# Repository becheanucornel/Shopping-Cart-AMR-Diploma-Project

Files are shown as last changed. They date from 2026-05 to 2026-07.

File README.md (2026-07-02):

# Shopping Cart AMR — Diploma Project







Robots have undeniably made our lives better. As years pass, new types of robots appear that assist humans even more. This project's objective is to develop a mobile robot capable of helping people inside supermarkets. The robot's purpose in this scenario is to replace the conventional shopping cart — eliminating the need to push or pull it around, and enabling wheelchair users to move more freely.

The robot is capable of autonomous navigation on a pre-built map, human/object detection and following using a YOLOv8 TensorRT model running at 207 FPS on the Jetson's GPU, and full remote control via a purpose-built web interface accessible from any device on the local network.

## System Architecture

### Hardware

| Component | Details |
|---|---|
| Compute | NVIDIA Jetson Orin Nano Super (8GB unified memory) |
| Motors | 2× 12V DC motors with quadrature encoders |
| Motor Drivers | 2× H-bridge motor driver modules |
| LiDARs | 4× SLAMTEC RPLIDAR C1 (one per corner, merged into a single scan) |
| Camera | Raspberry Pi Camera Module (CSI, 640×480 @ 30fps via GStreamer/Argus) |
| Chassis | Custom-designed in SolidWorks, 360×360mm differential drive base |

### Software Stack

| Layer | Technology |
|---|---|
| Robot OS | ROS2 Humble |
| Navigation | Nav2 (AMCL + NavFn planner + Regulated Pure Pursuit controller) |
| Localization | AMCL with pre-built map + EKF sensor fusion (wheel odometry + laser odometry) |
| Laser odometry | rf2o (scan-to-scan ICP, wheel-independent) |
| Object detection | YOLOv8n → TensorRT FP16 engine (207 FPS, 4.75ms GPU latency) |
| SLAM | slam_toolbox (used during mapping mode) |
| Web interface | Custom C++ Boost.Beast HTTP/WebSocket server + rosbridge |
| Build system | colcon / CMake |

## Packages

### Community packages
- **Nav2** — autonomous navigation stack (planner, controller, costmaps, behavior trees)
- **slam_toolbox** — online async SLAM for map creation
- **sllidar_ros2** — SLAMTEC LiDAR driver
- **rf2o_laser_odometry** — laser-based odometry, used alongside wheel encoders in the EKF
- **robot_localization** — EKF node fusing `/custom_odom_topic` (encoders) and `/odom_rf2o` (laser)

### Custom packages

#### `camera_module` (C++)
Publishes the Raspberry Pi camera stream to `/camera` using GStreamer/Argus at 30fps. Uses `SensorDataQoS` (Best Effort) to match downstream subscribers.

#### `human_detection_module` (C++)
YOLOv8n inference node running on TensorRT 10.3 FP16. On first launch it builds a serialized engine from `yolov8n.onnx` (takes ~10 minutes on first run, then cached permanently at `~/.ros/human_detection/yolov8n.engine`). Subsequent launches load the cached engine in under one second.

- Subscribes to `/camera` with `SensorDataQoS`
- Publishes `/yolo/debug_image` — live camera feed with bounding boxes drawn in real time
- Publishes `/yolo/target_pose` — 3D position of the tracked object in `camera_link` frame, estimated using the focal length and bounding box height
- Exposes `/detector/set_class` service (`std_srvs/SetBool`) — `false` = track person (class 0), `true` = track sports ball (class 32), for testing without a person present
- Parameters: `confidence_threshold` (0.50), `nms_threshold` (0.45), `focal_length_px` (500)

#### `mode_manager_module` (C++)
Central state machine managing the robot's five operating modes. Receives mode commands from the web UI on `/ui/mode/absolute` and routes velocity commands from the appropriate source to `/cmd_vel`.

| Mode | Velocity source | Behaviour |
|---|---|---|
| `IDLE` | — | Motors stopped |
| `MANUAL` | `/cmd_vel_teleop` | Joystick/D-pad from web UI |
| `MAPPING` | `/cmd_vel_teleop` | Manual drive while slam_toolbox builds a map |
| `NAVIGATION` | `/cmd_vel_nav2` | Autonomous point-to-point navigation via Nav2 |
| `FOLLOWING` | `/cmd_vel_nav2` | Follows the detected target using Nav2 as the path executor |

Switching out of `MAPPING` automatically saves the map, stops slam_toolbox, and reactivates AMCL. Switching out of `NAVIGATION` or `FOLLOWING` cancels any active Nav2 goal.

#### `scan_merger_module` (C++)
Merges the four LiDAR scans (front-left, front-right, back-left, back-right) into a single `/scan` topic in the `custom_base_link` frame. Uses cached TF transforms for zero-overhead merging at runtime.

#### `web_server` (C++)
Custom HTTP server built with Boost.Beast that hosts the robot control interface. No external web server or framework needed — the binary serves static files and handles all API calls and MJPEG streams directly.

Endpoints:
- `GET /` — main control page
- `GET /stream/camera` — MJPEG stream of the raw `/camera` topic (~20 FPS cap)
- `GET /stream/debug` — MJPEG stream of `/yolo/debug_image` with bounding box overlay
- `GET /api/robot/state` — current robot state as JSON
- `GET /api/robot/mode` — current mode as JSON
- WebSocket (via rosbridge on port 9090) — map data, odometry, mode commands, nav goals

#### `robot_driver` (Python)
Motor controller node managing GPIO PWM output to the two H-bridge drivers and reading quadrature encoder ticks to compute wheel odometry. Publishes to `/custom_odom_topic` (`nav_msgs/Odometry`). The EKF node is the sole publisher of the `custom_odom → custom_base_link` TF transform.

#### `system_bringup`
Launch file, Nav2/AMCL/EKF configuration, URDF robot description, pre-built map, behavior trees, and RViz config. The launch sequence is staged to ensure hardware initializes in the correct order before navigation nodes start.

## TF Tree

```
map
 └── custom_odom          ← AMCL publishes map→custom_odom
      └── custom_base_link ← EKF publishes custom_odom→custom_base_link
           ├── camera_link
           ├── lidar_front_left
           ├── lidar_front_right
           ├── lidar_back_left
           └── lidar_back_right
```

## Launch Sequence

The system starts in 6 staged steps to prevent race conditions between hardware init and software dependencies:

```
Stage 1  — Robot state publisher (URDF → TF static transforms)
Stage 2  — 4× LiDAR nodes (staggered 1s apart)
Stage 2.5 — Scan merger, motor controller, camera publisher
Stage 2.75 — rf2o laser odometry, EKF node
Stage 3  — AMCL + map server (localization active)
Stage 4  — Nav2 composable container
Stage 5  — Nav2 nodes (controller, planner, behavior server, bt_navigator)
Stage 6  — Web server, rosbridge, YOLO detection node, RViz
```

```bash
# Build
cd ~/Projects/Shopping-Cart-AMR-Diploma-Project
colcon build --symlink-install
source install/setup.bash

# First launch only: build the TensorRT engine outside ROS
# (takes ~10 minutes, cached permanently afterwards)
/usr/src/tensorrt/bin/trtexec \
  --onnx=src/human_detection_module/model/yolov8n.onnx \
  --saveEngine=/home/$USER/.ros/human_detection/yolov8n.engine \
  --fp16

# Launch everything
ros2 launch system_bringup robot_system.launch.py
```

Then open `http://<jetson-ip>:8080` in any browser on the same network.

## Web Interface

The control interface runs entirely in the browser with no installation required.

| Panel | Function |
|---|---|
| **IDLE** | Standby screen with animated status ring |
| **MANUAL** | Live camera feed + D-pad + speed slider (0.1–1.0 m/s) |
| **NAVIGATE** | ROS2D.js map + coordinate input + dispatch/abort goal buttons |
| **FOLLOW** | Detection feed with bounding boxes + target selector (Human / Sports Ball) + Start/Stop Following |

## Robot 3D Model

The robot has been designed entirely in SolidWorks. It consists of two main assemblies:

- **Robot Base** — main structural body holding the motors, LiDARs, caster wheels, and shopping basket mount
- **Robot Panel** — internal panel designed to house all electrical components

<p float="left">
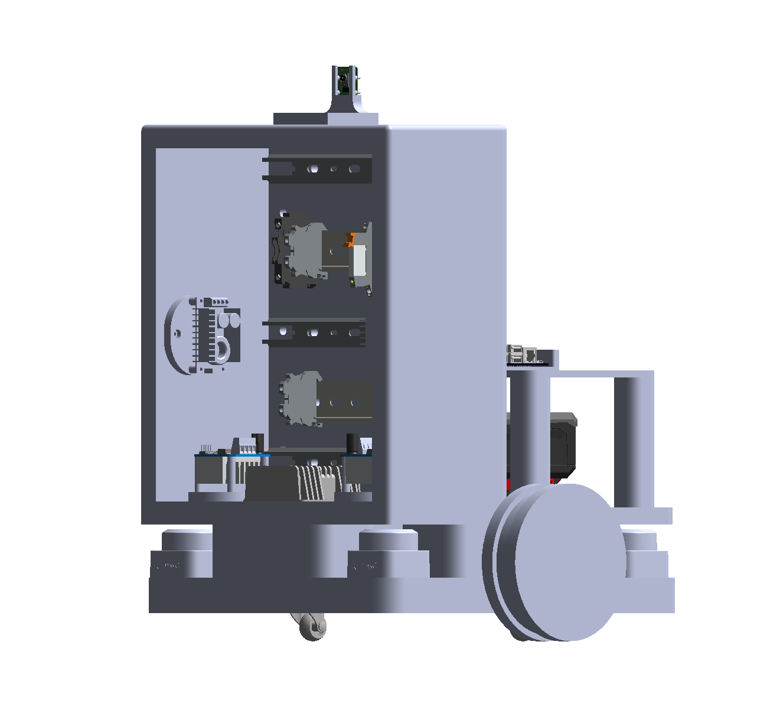
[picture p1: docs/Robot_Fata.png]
  
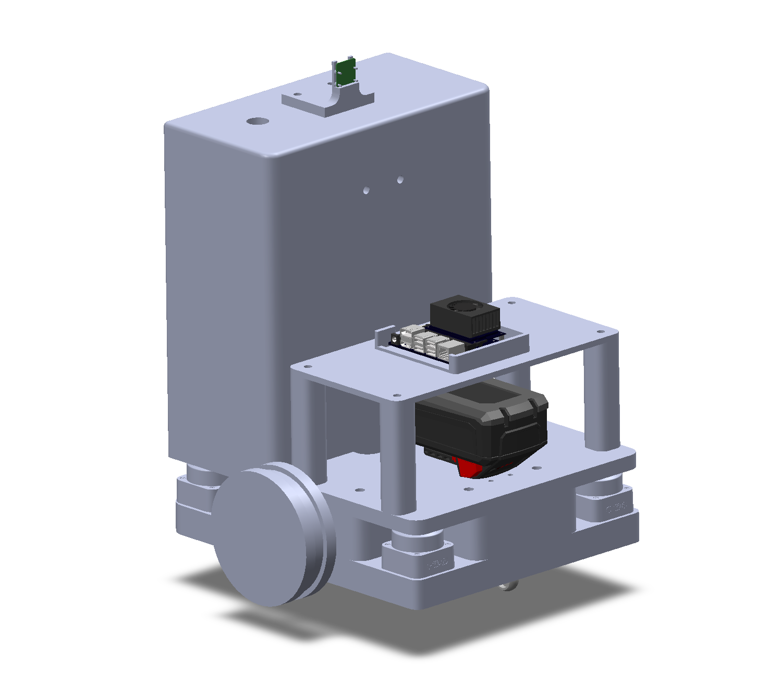
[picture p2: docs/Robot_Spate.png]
  
</p>

## Results

Demonstrations of the robot performing on hardware.

### Localization

Localization (https://www.youtube.com/watch?v=b-eXOFlw1KQ)

### Navigation to a Target

Navigation to a Target (https://www.youtube.com/watch?v=DEMlTes20ME)

### Dynamic Point Follower

Dynamic Point Follower (https://www.youtube.com/watch?v=rmnldiNaGu0)

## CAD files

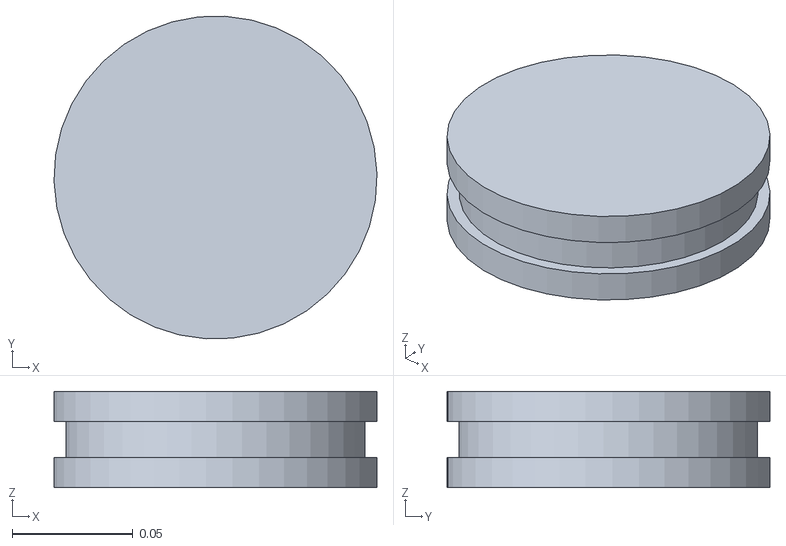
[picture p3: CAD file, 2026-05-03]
src/system_bringup/meshes/right_wheel.STL
0.134 x 0.134 x 0.04

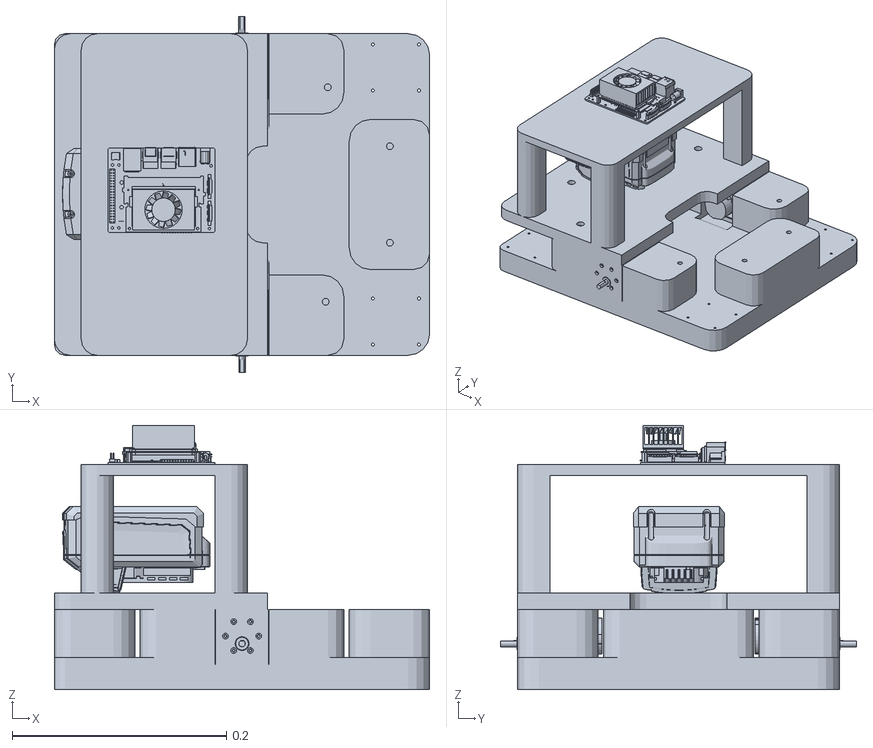
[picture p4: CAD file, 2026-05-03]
src/system_bringup/meshes/base_link.STL
0.35 x 0.332 x 0.247

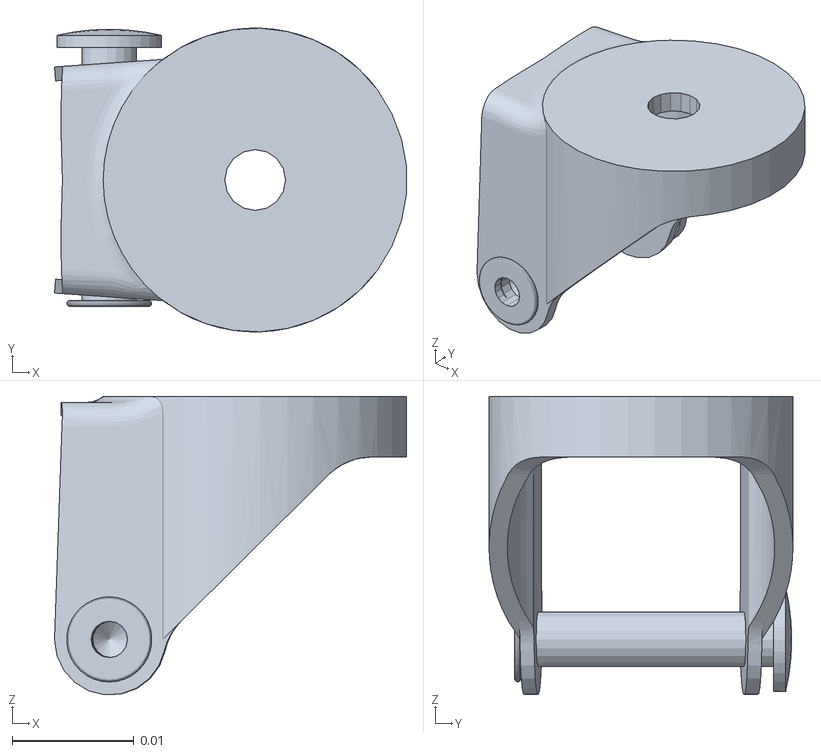
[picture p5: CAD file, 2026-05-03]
src/system_bringup/meshes/back_caster.STL
0.029 x 0.025 x 0.0245

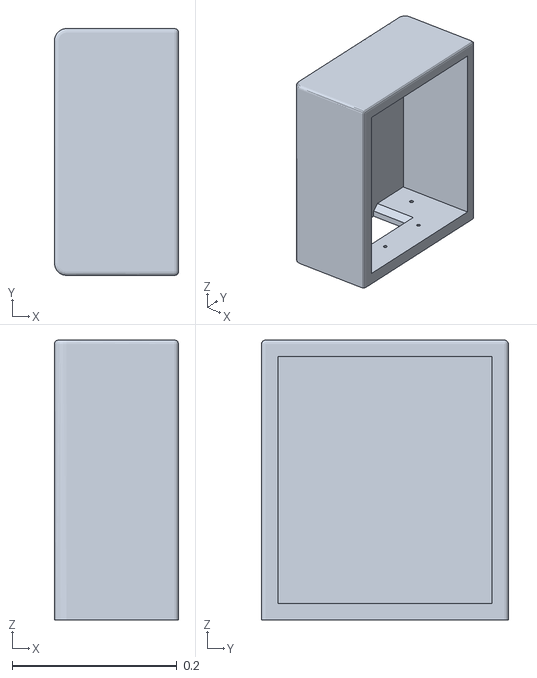
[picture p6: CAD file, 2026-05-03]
src/system_bringup/meshes/top_link.STL
0.151 x 0.3 x 0.34

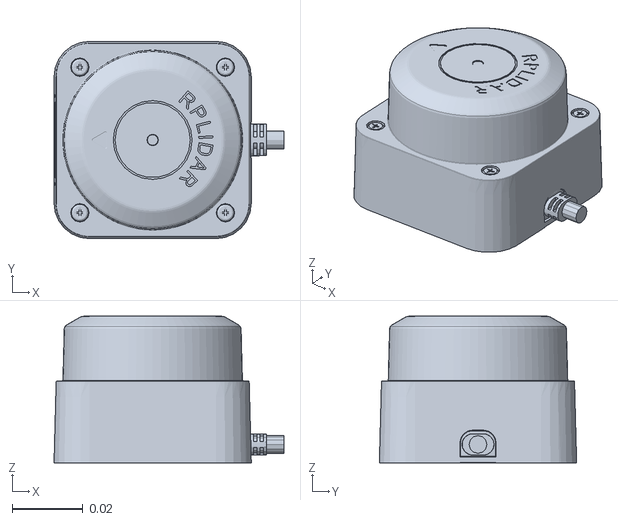
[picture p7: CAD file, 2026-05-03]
src/system_bringup/meshes/lidar_back_right.STL
0.0648 x 0.0556 x 0.0413

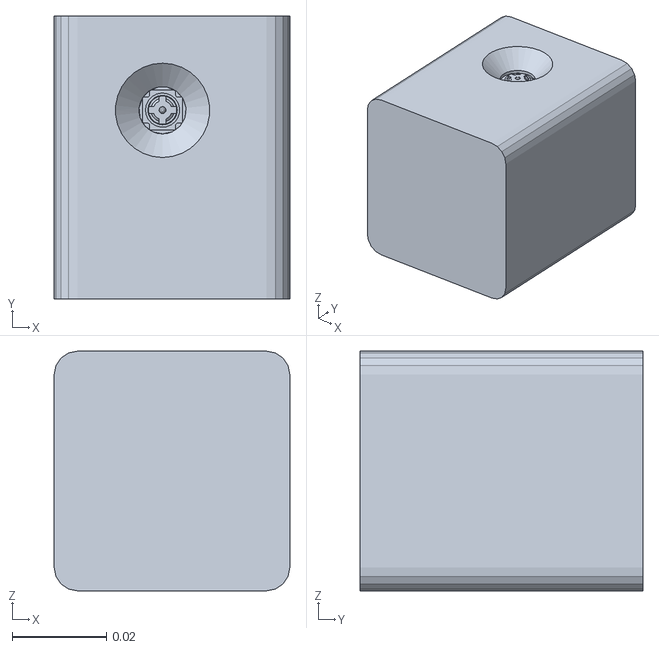
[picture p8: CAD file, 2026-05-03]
src/system_bringup/meshes/camera_link.STL
0.05 x 0.06 x 0.0508

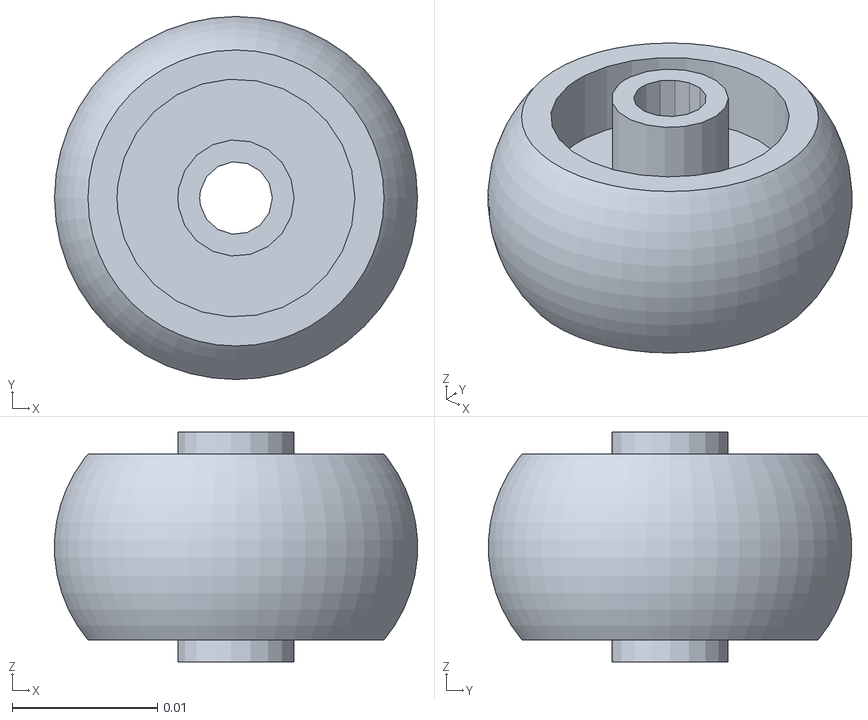
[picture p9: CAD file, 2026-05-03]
src/system_bringup/meshes/front_caster_wheel.STL
0.025 x 0.025 x 0.0158

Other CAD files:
src/system_bringup/meshes/lidar_front_right.STL
src/system_bringup/meshes/left_wheel.STL
src/system_bringup/meshes/lidar_back_left.STL
src/system_bringup/meshes/front_caster.STL
src/system_bringup/meshes/lidar_front_left.STL

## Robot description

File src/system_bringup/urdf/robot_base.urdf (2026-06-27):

<?xml version="1.0" encoding="utf-8"?>
<robot name="URDF_RobotDiploma">

  <link name="custom_base_footprint"/>

  <joint name="base_footprint_joint" type="fixed">
    <parent link="custom_base_footprint"/>
    <child link="custom_base_link"/>
    <origin xyz="0 0 0.05" rpy="0 0 0"/> 
  </joint>

  <link name="custom_base_link">
    <visual>
      <origin xyz="0 0 0" rpy="0 0 0" />
      <geometry>
        <mesh filename="package://system_bringup/meshes/base_link.STL" />
      </geometry>
      <material name=""><color rgba="0.79 0.82 0.93 1" /></material>
    </visual>
    <collision>
      <origin xyz="0 0 0.1" rpy="0 0 0" />
      <geometry>
        <box size="0.4 0.44 0.2"/> 
      </geometry>
    </collision>
  </link>

  <link name="left_wheel">
    <visual>
      <geometry><mesh filename="package://system_bringup/meshes/left_wheel.STL" /></geometry>
      <material name=""><color rgba="0.79 0.82 0.93 1" /></material>
    </visual>
    <collision>
      <origin xyz="0 0 0" rpy="0 0 0" />
      <geometry><cylinder radius="0.067" length="0.04"/></geometry>
    </collision>
  </link>

  <joint name="leftwheel" type="continuous">
    <origin xyz="0.00033999 0.194 0.013" rpy="1.5708 0 0" />
    <parent link="custom_base_link" />
    <child link="left_wheel" />
    <axis xyz="0 0 -1" />
  </joint>

  <link name="right_wheel">
    <visual>
      <geometry><mesh filename="package://system_bringup/meshes/right_wheel.STL" /></geometry>
      <material name=""><color rgba="0.79 0.82 0.93 1" /></material>
    </visual>
    <collision>
      <origin xyz="0 0 0" rpy="0 0 0" />
      <geometry><cylinder radius="0.067" length="0.04"/></geometry>
    </collision>
  </link>

  <joint name="rightwheel" type="continuous">
    <origin xyz="0.00045567 -0.194 0.013" rpy="1.5708 0 0" />
    <parent link="custom_base_link" />
    <child link="right_wheel" />
    <axis xyz="0 0 1" />
  </joint>

  <link name="front_caster">
    <visual>
      <geometry><mesh filename="package://system_bringup/meshes/front_caster.STL" /></geometry>
    </visual>
  </link>
  <joint name="frontcasterjoint" type="fixed">
    <origin xyz="0.1283 0 -0.0243" rpy="0 0 0" />
    <parent link="custom_base_link" />
    <child link="front_caster" />
  </joint>

  <link name="back_caster">
    <visual>
      <geometry><mesh filename="package://system_bringup/meshes/back_caster.STL" /></geometry>
    </visual>
  </link>
  <joint name="backcasterjoint" type="fixed">
    <origin xyz="-0.1267 0 -0.0243" rpy="0 0 0" />
    <parent link="custom_base_link" />
    <child link="back_caster" />
  </joint>

  <link name="lidar_front_right">
    <visual><geometry><mesh filename="package://system_bringup/meshes/lidar_front_right.STL" /></geometry></visual>
  </link>
  <joint name="lidar1" type="fixed">
    <origin xyz="0.1438 -0.1185 0.0232" rpy="0 0 3.14159" /> 
    <parent link="custom_base_link" />
    <child link="lidar_front_right" />
  </joint>

  <link name="lidar_front_left">
    <visual><geometry><mesh filename="package://system_bringup/meshes/lidar_front_left.STL" /></geometry></visual>
  </link>
  <joint name="lidar2" type="fixed">
    <origin xyz="0.1439 0.1185 0.0232" rpy="0 0 3.14159" />
    <parent link="custom_base_link" />
    <child link="lidar_front_left" />
  </joint>

  <link name="lidar_back_left">
    <visual><geometry><mesh filename="package://system_bringup/meshes/lidar_back_left.STL" /></geometry></visual>
  </link>
  <joint name="lidar3" type="fixed">
    <origin xyz="-0.1431 0.1185 0.0232" rpy="0 0 0" />
    <parent link="custom_base_link" />
    <child link="lidar_back_left" />
  </joint>

  <link name="lidar_back_right">
    <visual><geometry><mesh filename="package://system_bringup/meshes/lidar_back_right.STL" /></geometry></visual>
  </link>
  <joint name="lidar4" type="fixed">
    <origin xyz="-0.1431 -0.1185 0.0232" rpy="0 0 0" />
    <parent link="custom_base_link" />
    <child link="lidar_back_right" />
  </joint>

  <link name="top_link">
    <visual><geometry><mesh filename="package://system_bringup/meshes/top_link.STL" /></geometry></visual>
  </link>
  <joint name="toplinkjoint" type="fixed">
    <origin xyz="0.1179 0 0.065" rpy="0 0 0" />
    <parent link="custom_base_link" />
    <child link="top_link" />
  </joint>

  <link name="camera_link">
    <visual><geometry><mesh filename="package://system_bringup/meshes/camera_link.STL" /></geometry></visual>
  </link>
  <joint name="camera_joint" type="fixed">
    <origin xyz="0.0324 -0.002 0.36" rpy="1.5708 0 1.5708" />
    <parent link="top_link" />
    <child link="camera_link" />
  </joint>

</robot>

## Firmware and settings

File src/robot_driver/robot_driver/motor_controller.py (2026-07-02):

import rclpy
from rclpy.node import Node
from geometry_msgs.msg import Twist
from nav_msgs.msg import Odometry
import Jetson.GPIO as GPIO
import time
import threading
import math
import os

os.environ["JETSON_GPIO_PINMUX_CHECK"] = "0"

class SoftwarePWM:
    def __init__(self, pin, frequency):
        self.pin = pin
        self.frequency = frequency
        self.duty_cycle = 0.0
        self.is_running = False
        self.thread = None
        GPIO.setup(self.pin, GPIO.OUT)
        GPIO.output(self.pin, GPIO.LOW)

    def start(self, duty_cycle):
        self.duty_cycle = duty_cycle
        self.is_running = True
        self.thread = threading.Thread(target=self._run_pwm, daemon=True)
        self.thread.start()

    def ChangeDutyCycle(self, duty_cycle):
        self.duty_cycle = max(0.0, min(100.0, duty_cycle))

    def stop(self):
        self.is_running = False
        if self.thread: self.thread.join()
        GPIO.output(self.pin, GPIO.LOW)

    def _run_pwm(self):
        period = 1.0 / self.frequency
        while self.is_running:
            if self.duty_cycle <= 0.0:
                GPIO.output(self.pin, GPIO.LOW)
                time.sleep(period)
            elif self.duty_cycle >= 100.0:
                GPIO.output(self.pin, GPIO.HIGH)
                time.sleep(period)
            else:
                time_high = period * (self.duty_cycle / 100.0)
                time_low = period - time_high
                GPIO.output(self.pin, GPIO.HIGH)
                time.sleep(time_high)
                GPIO.output(self.pin, GPIO.LOW)
                time.sleep(time_low)

class AmrMotorNode(Node):
    def __init__(self):
        super().__init__('amr_motor_controller')

        self.PIN_M1_FWD, self.PIN_M1_REV = 32, 7
        self.PIN_M2_FWD, self.PIN_M2_REV = 33, 15
        self.PWM_FREQ = 1000

        self.PIN_ENC_L, self.PIN_ENC_L_B = 11, 12
        self.PIN_ENC_R, self.PIN_ENC_R_B = 16, 18

        self.declare_parameter('wheel_radius',       0.067)
        self.declare_parameter('wheelbase',          0.39)
        self.declare_parameter('ticks_per_rev',      1440.0)
        # Speed limits applied to incoming cmd_vel
        self.declare_parameter('max_linear_speed',   0.2)   # m/s
        self.declare_parameter('max_angular_speed',  0.6)   # rad/s
        # Acceleration/deceleration limits (units per second)
        self.declare_parameter('linear_accel_limit',  0.15)  # m/s²
        self.declare_parameter('linear_decel_limit',  1.5)   # m/s² — faster stop
        self.declare_parameter('angular_accel_limit', 0.5)   # rad/s²
        self.declare_parameter('angular_decel_limit', 3.0)   # rad/s²
        self.declare_parameter('pwm_scale',          1.0)   # 1.0 m/s = 100% PWM
        self.declare_parameter('cmd_vel_timeout',    0.5)

        self.R = self.get_parameter('wheel_radius').value
        self.L = self.get_parameter('wheelbase').value
        self.N = self.get_parameter('ticks_per_rev').value
        self.max_v   = self.get_parameter('max_linear_speed').value
        self.max_w   = self.get_parameter('max_angular_speed').value
        self.acc_v   = self.get_parameter('linear_accel_limit').value
        self.dec_v   = self.get_parameter('linear_decel_limit').value
        self.acc_w   = self.get_parameter('angular_accel_limit').value
        self.dec_w   = self.get_parameter('angular_decel_limit').value
        self.pwm_scale = self.get_parameter('pwm_scale').value
        self.cmd_timeout = self.get_parameter('cmd_vel_timeout').value

        # Velocity ramp state
        self.target_v = 0.0
        self.target_w = 0.0
        self.current_v = 0.0
        self.current_w = 0.0
        self.last_cmd_time = self.get_clock().now()

        self.left_ticks = 0
        self.right_ticks = 0
        self.prev_left_ticks = 0
        self.prev_right_ticks = 0

        self.x, self.y, self.theta = 0.0, 0.0, 0.0
        self.last_time = self.get_clock().now()

        self.odom_pub = self.create_publisher(Odometry, 'custom_odom_topic', 10)

        GPIO.setwarnings(False)
        GPIO.setmode(GPIO.BOARD)

        self.pwm_m1_rev = SoftwarePWM(self.PIN_M1_REV, self.PWM_FREQ)
        self.pwm_m1_rev.start(0)
        GPIO.setup(self.PIN_M1_FWD, GPIO.OUT)
        self.pwm_m1_fwd = GPIO.PWM(self.PIN_M1_FWD, self.PWM_FREQ)
        self.pwm_m1_fwd.start(0)

        self.pwm_m2_rev = SoftwarePWM(self.PIN_M2_REV, self.PWM_FREQ)
        self.pwm_m2_rev.start(0)
        GPIO.setup(self.PIN_M2_FWD, GPIO.OUT)
        self.pwm_m2_fwd = GPIO.PWM(self.PIN_M2_FWD, self.PWM_FREQ)
        self.pwm_m2_fwd.start(0)

        GPIO.setup([self.PIN_ENC_L, self.PIN_ENC_L_B, self.PIN_ENC_R, self.PIN_ENC_R_B], GPIO.IN)
        GPIO.add_event_detect(self.PIN_ENC_L, GPIO.BOTH, callback=self.left_tick_cb)
        GPIO.add_event_detect(self.PIN_ENC_R, GPIO.BOTH, callback=self.right_tick_cb)

        self._enc_diag_timer = self.create_timer(5.0, self._check_encoder_health)
        self._enc_l_count_last = 0
        self._enc_r_count_last = 0

        self.create_subscription(Twist, '/cmd_vel', self.cmd_vel_callback, 10)
        self.create_timer(0.05, self.update_odometry)

    def _check_encoder_health(self):
        dl = abs(self.left_ticks - self._enc_l_count_last)
        dr = abs(self.right_ticks - self._enc_r_count_last)
        self._enc_l_count_last = self.left_ticks
        self._enc_r_count_last = self.right_ticks
        if dl > 10 and dr == 0:
            self.get_logger().error(
                f'RIGHT ENCODER DEAD! left_ticks={dl} right_ticks={dr} in last 5s. '
                f'Check wiring on BOARD pin {self.PIN_ENC_R}. Odometry is WRONG!')
        elif dr > 10 and dl == 0:
            self.get_logger().error(
                f'LEFT ENCODER DEAD! left_ticks={dl} right_ticks={dr} in last 5s. '
                f'Check wiring on BOARD pin {self.PIN_ENC_L}. Odometry is WRONG!')
        elif dl > 5 or dr > 5:
            self.get_logger().info(f'Encoder health OK: L={dl} R={dr} ticks/5s')

    def left_tick_cb(self, channel):
        if GPIO.input(self.PIN_ENC_L) != GPIO.input(self.PIN_ENC_L_B):
            self.left_ticks += 1
        else:
            self.left_ticks -= 1

    def right_tick_cb(self, channel):
        if GPIO.input(self.PIN_ENC_R) == GPIO.input(self.PIN_ENC_R_B):
            self.right_ticks += 1
        else:
            self.right_ticks -= 1

    def cmd_vel_callback(self, msg):
        # Clamp incoming velocity to configured limits
        self.target_v = max(-self.max_v, min(self.max_v, msg.linear.x))
        self.target_w = max(-self.max_w, min(self.max_w, msg.angular.z))
        self.last_cmd_time = self.get_clock().now()

    def _ramp(self, current, target, accel, decel, dt):
        delta = target - current
        # Deceleration: moving toward zero or reversing direction
        slowing = (current > 0 and target < current) or (current < 0 and target > current)
        limit = decel if slowing else accel
        max_step = limit * dt
        if abs(delta) <= max_step:
            return target
        return current + math.copysign(max_step, delta)

    def _apply_velocities(self, v, w):
        v_l = v - (w * self.L / 2.0)
        v_r = v + (w * self.L / 2.0)
        self.apply_pwm(self.pwm_m1_fwd, self.pwm_m1_rev, v_l * 100.0 / self.pwm_scale)
        self.apply_pwm(self.pwm_m2_fwd, self.pwm_m2_rev, v_r * 100.0 / self.pwm_scale)

    def apply_pwm(self, fwd, rev, speed):
        pwm = max(-100, min(100, speed))
        if pwm > 0:
            rev.ChangeDutyCycle(0)
            fwd.ChangeDutyCycle(pwm)
        else:
            fwd.ChangeDutyCycle(0)
            rev.ChangeDutyCycle(abs(pwm))

    def update_odometry(self):
        current_time = self.get_clock().now()
        dt = (current_time - self.last_time).nanoseconds / 1e9

        if dt <= 0.0:
            return

        # Stop if cmd_vel has gone stale
        elapsed_since_cmd = (current_time - self.last_cmd_time).nanoseconds / 1e9
        if elapsed_since_cmd > self.cmd_timeout:
            self.target_v = 0.0
            self.target_w = 0.0

        # Ramp current velocities toward targets
        self.current_v = self._ramp(self.current_v, self.target_v, self.acc_v, self.dec_v, dt)
        self.current_w = self._ramp(self.current_w, self.target_w, self.acc_w, self.dec_w, dt)

        # Drive motors at ramped velocity
        self._apply_velocities(self.current_v, self.current_w)

        dl = self.left_ticks - self.prev_left_ticks
        dr = self.right_ticks - self.prev_right_ticks
        self.prev_left_ticks, self.prev_right_ticks = self.left_ticks, self.right_ticks

        d_left  = 2 * math.pi * self.R * (dl / self.N)
        d_right = 2 * math.pi * self.R * (dr / self.N)
        ds      = (d_right + d_left) / 2.0
        d_theta = (d_right - d_left) / self.L

        v     = ds / dt
        omega = d_theta / dt

        if abs(dl) > 0 or abs(dr) > 0:
            self.get_logger().info(f'dt={dt:.4f} dl={dl} dr={dr} ds={ds:.4f} v={v:.4f} omega={omega:.4f}')

        self.theta += d_theta
        self.x += ds * math.cos(self.theta)
        self.y += ds * math.sin(self.theta)
        self.last_time = current_time

        odom = Odometry()
        odom.header.stamp    = current_time.to_msg()
        odom.header.frame_id = 'custom_odom'
        odom.child_frame_id  = 'custom_base_footprint'

        odom.pose.pose.position.x    = self.x
        odom.pose.pose.position.y    = self.y
        odom.pose.pose.orientation.z = math.sin(self.theta / 2.0)
        odom.pose.pose.orientation.w = math.cos(self.theta / 2.0)

        odom.twist.twist.linear.x  = v
        odom.twist.twist.angular.z = omega

        odom.pose.covariance[0]  = 0.1
        odom.pose.covariance[7]  = 0.1
        odom.pose.covariance[14] = 1e9
        odom.pose.covariance[21] = 1e9
        odom.pose.covariance[28] = 1e9
        odom.pose.covariance[35] = 0.2
        odom.twist.covariance[0]  = 0.05
        odom.twist.covariance[7]  = 1e9
        odom.twist.covariance[14] = 1e9
        odom.twist.covariance[21] = 1e9
        odom.twist.covariance[28] = 1e9
        odom.twist.covariance[35] = 0.2

        self.odom_pub.publish(odom)

    def cleanup(self):
        self.pwm_m1_rev.stop(); self.pwm_m1_fwd.stop()
        self.pwm_m2_rev.stop(); self.pwm_m2_fwd.stop()
        GPIO.cleanup()

def main(args=None):
    rclpy.init(args=args)
    node = AmrMotorNode()
    try: rclpy.spin(node)
    except KeyboardInterrupt: pass
    finally:
        node.cleanup()
        rclpy.shutdown()

if __name__ == '__main__': main()

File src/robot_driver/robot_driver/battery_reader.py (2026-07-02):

import rclpy
from rclpy.node import Node
from std_msgs.msg import Float32

import board
import busio
from adafruit_ads1x15.ads1115 import ADS1115
from adafruit_ads1x15.analog_in import AnalogIn

class BatteryMonitorNode(Node):
    def __init__(self):
        super().__init__('battery_monitor_node')
    
        self.declare_parameter('r1', 100000.0)
        self.declare_parameter('r2', 10000.0)
        
        self.r1 = self.get_parameter('r1').value
        self.r2 = self.get_parameter('r2').value
        self.divider_ratio = (self.r1 + self.r2) / self.r2
        
        self.publisher_ = self.create_publisher(Float32, 'battery_voltage', 10)
        
        try:
            self.i2c = busio.I2C(board.SCL, board.SDA)
            
            self.ads = ADS1115(self.i2c)
            
            self.ads.gain = 1 
            
            self.chan = AnalogIn(self.ads, 0)
            
            self.get_logger().info('Python Battery Monitor Started. Listening on A0...')
        except Exception as e:
            self.get_logger().error(f'Failed to initialize I2C or ADC: {e}')
            return

        self.timer = self.create_timer(0.1, self.publish_voltage)

    def publish_voltage(self):
        try:
            adc_voltage = self.chan.voltage
            
            battery_voltage = adc_voltage * self.divider_ratio
            
            self.get_logger().info(f'Raw A0: {adc_voltage:.3f}V | Multiplier: {self.divider_ratio:.1f} | Output: {battery_voltage:.2f}V')
            
            msg = Float32()
            msg.data = float(battery_voltage)
            self.publisher_.publish(msg)
            
        except Exception as e:
            self.get_logger().warning(f'Failed to read ADC: {e}')

def main(args=None):
    rclpy.init(args=args)
    node = BatteryMonitorNode()
    
    if hasattr(node, 'ads'):
        rclpy.spin(node)
        
    node.destroy_node()
    rclpy.shutdown()

if __name__ == '__main__':
    main()

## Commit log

2026-05-03 version 1.0.0
    [back_caster.STL, back_caster_wheel.STL, base_link.STL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]
2026-05-26 version 1.1.3
    [robot_base.urdf]
2026-06-02 version 2.0.0
    [robot_base.urdf]
2026-06-27 version 2.0.1
    [robot_base.urdf]
